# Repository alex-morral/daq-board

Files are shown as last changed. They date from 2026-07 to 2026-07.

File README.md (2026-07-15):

# DAQ Board — General-Purpose Data Acquisition Board

A 2-layer, USB-C powered **data acquisition board** built around an STM32F103,
designed from scratch in Altium, manufactured at JLCPCB, and brought up with
bare-metal firmware. It measures real-world analog signals (16-bit ADC),
generates analog output (12-bit DAC), reads temperature to ±0.1 °C, stores data
to SPI flash, and streams everything to a live browser dashboard over USB.

> Portfolio project #2 of 3 (FPGA → **PCB** → Embedded). Focus: the full
> hardware flow — schematic → layout → fabrication → bring-up → firmware.

---

## What it demonstrates

- **Mixed-signal PCB design** in Altium: analog (ADC/DAC/LDO) + digital (MCU/flash)
- **Multiple buses**: I²C, SPI, UART, USB
- **Full manufacturing flow**: DRC → Gerbers → JLCPCB assembly → DFM
- **A pin-by-pin schematic audit before paying** that caught a real error (R5)
- **Bare-metal firmware** (no HAL): direct register access, custom linker script
  and startup, driver code for every peripheral
- **A live web instrument**: Node serial bridge + WebSocket + custom canvas UI

---

## 1 · Design (Altium Designer)

The schematic — mixed-signal, six functional blocks (power, MCU, USB, I²C, SPI
flash, LEDs/SWD):

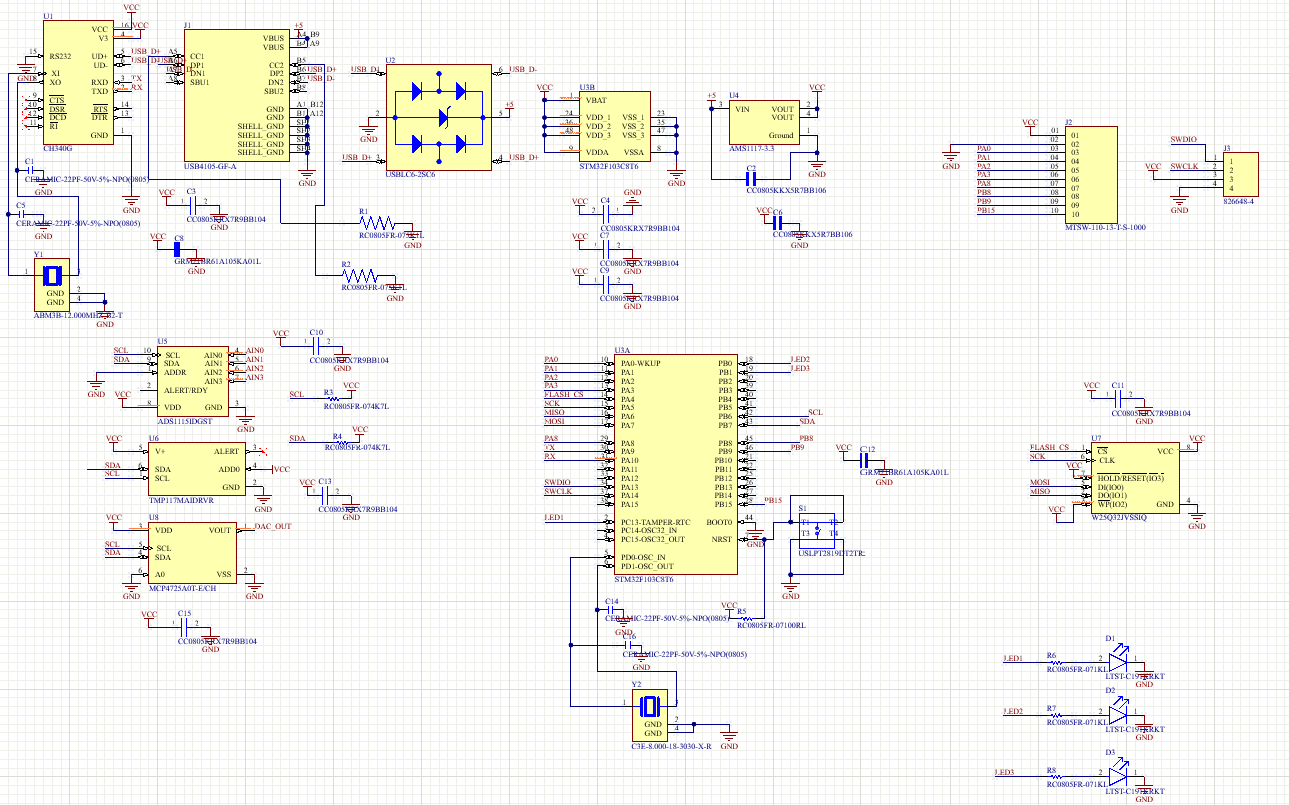
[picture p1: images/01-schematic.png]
Schematic


Board layout (2 layers, 59.94 × 40.01 mm) and 3D render:

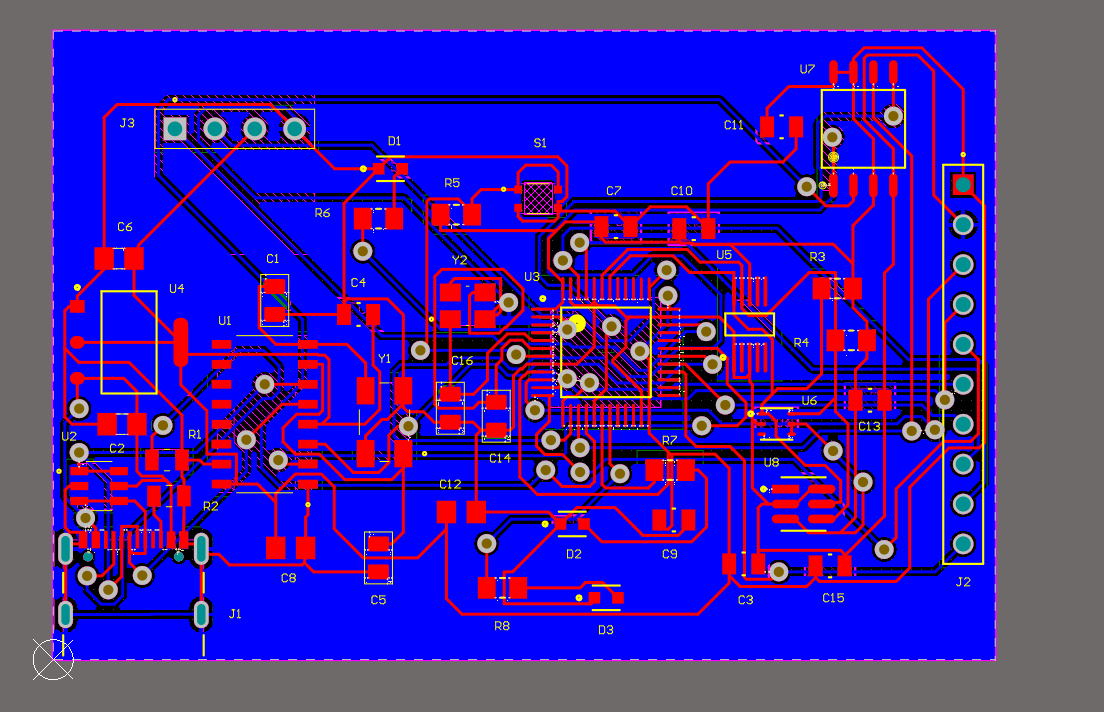
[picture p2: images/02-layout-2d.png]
2D layout

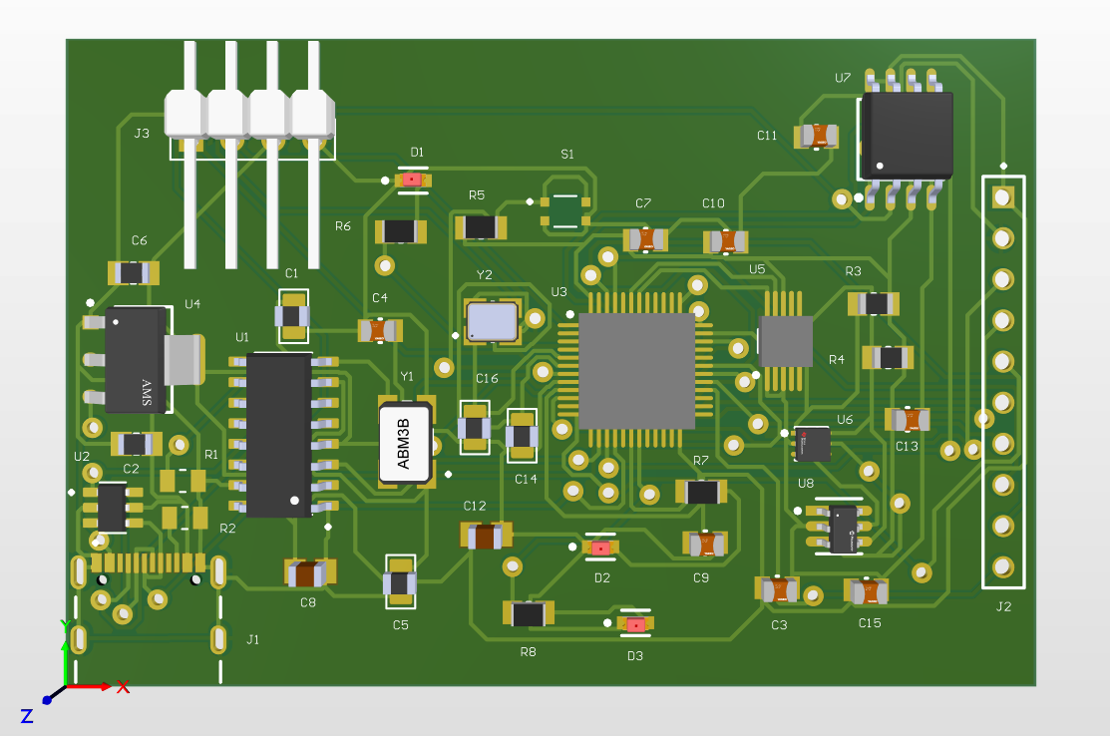
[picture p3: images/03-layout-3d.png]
3D render


Design Rule Check clean. Worth noting: the Situs auto-router reported
"135/135 100%", but DRC then revealed **23 shorts + 30 clearance violations** →
Unroute All + hand-routing to the clean result below:

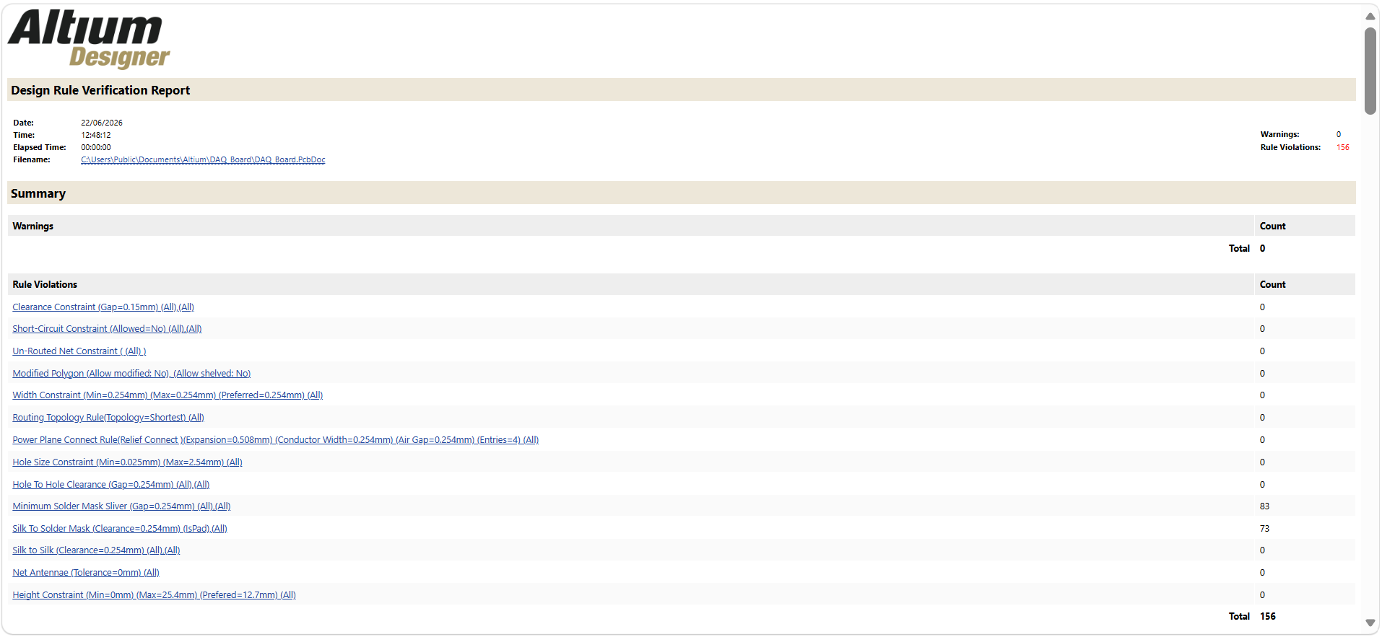
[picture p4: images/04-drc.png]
DRC clean


### The schematic audit (the interesting part)

Before paying for assembly, the whole schematic was audited **pin by pin against
datasheets**, block by block. Result: a healthy design with **one real error**.

- **Power (AMS1117):** VIN/VOUT/GND correct, tab tied to VOUT (the classic 1117
  trap — here done right), 10 µF in/out.
- **STM32:** all VDD/VDDA→VCC, VSS→GND, BOOT0→GND, clock OK.
  **🔴 R5 was 100 Ω → should be 10 kΩ (NRST pull-up). Caught and corrected.**
- **USB:** UART cross correct (CH340 RXD→TX), CH340 at 3.3 V, USBLC6 with no
  D+/D− short, R1/R2 = 5.1 kΩ.
- **I²C:** addresses verified collision-free → `0x48` / `0x49` / `0x60`
  (MCP4725 is the **A0** variant → `0x60`, *not* `0x62`). Pull-ups 4.7 kΩ.
- **SPI flash:** `/HOLD` and `/WP` tied to VCC (critical for the W25Q32).

---

## 2 · Manufacturing (JLCPCB)

DFM placement review before assembly — top and bottom:

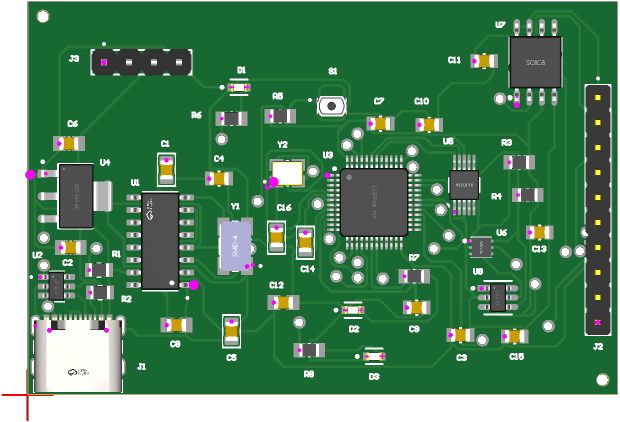
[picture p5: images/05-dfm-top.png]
DFM top

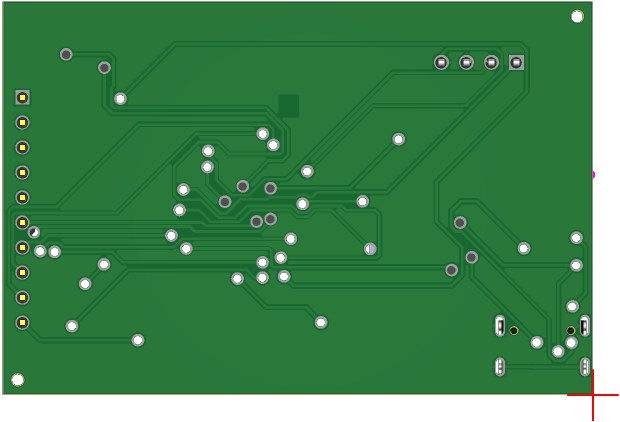
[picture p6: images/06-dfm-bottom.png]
DFM bottom


Five assembled boards, straight from the fab:

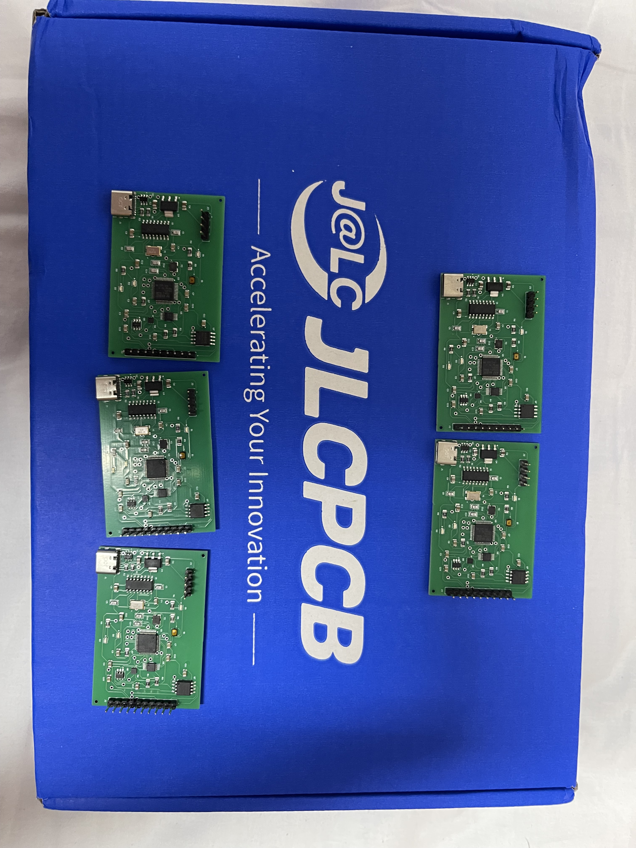
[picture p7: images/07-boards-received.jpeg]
5 assembled boards


---

## 3 · The board

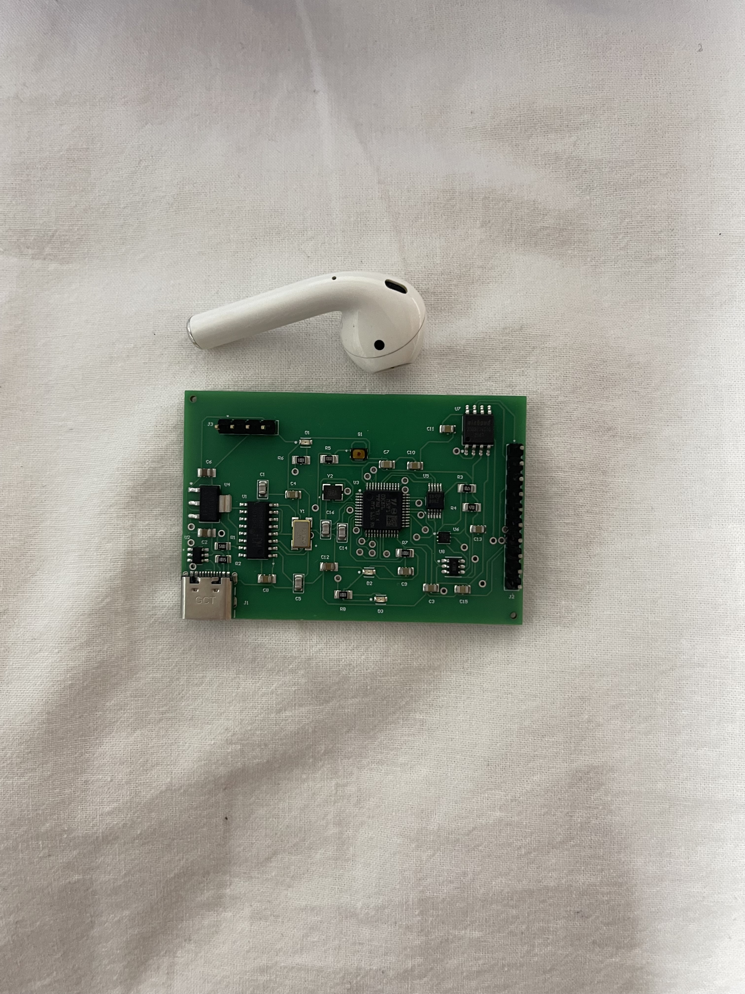
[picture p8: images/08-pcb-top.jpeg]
PCB top

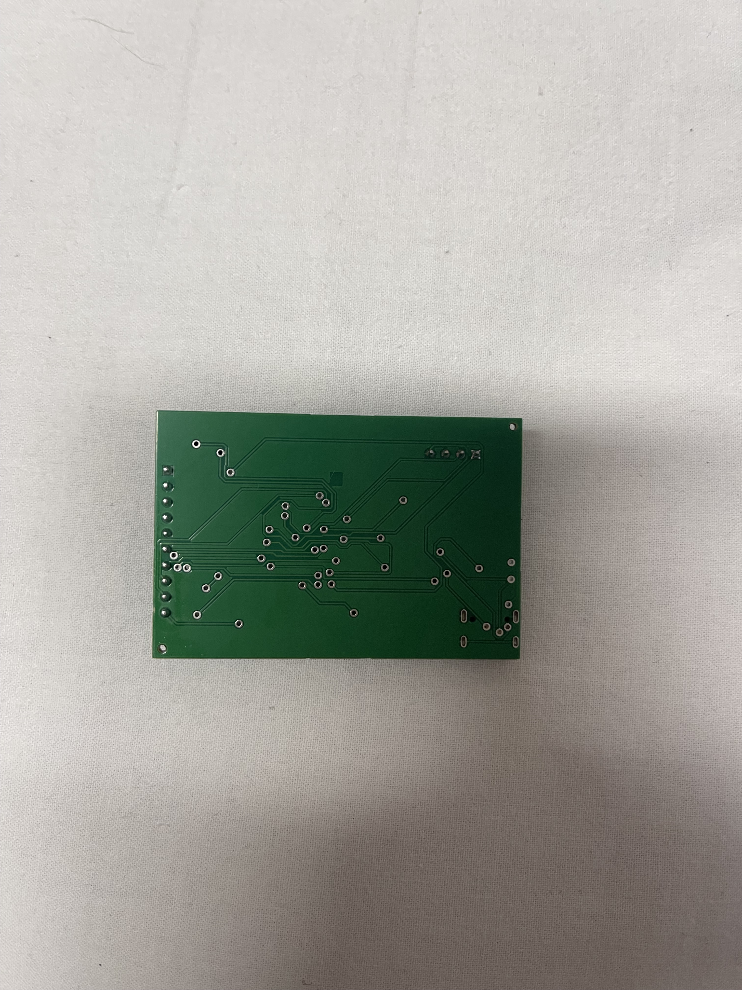
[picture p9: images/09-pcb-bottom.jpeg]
PCB bottom


| Component | Ref | Function | Bus / Address |
|---|---|---|---|
| STM32F103C8T6 | U3 | MCU (Cortex-M3, 72 MHz) | — |
| ADS1115 | U5 | 16-bit ADC, 4 channels | I²C `0x48` |
| TMP117 | U6 | Precision temp sensor (±0.1 °C) | I²C `0x49` |
| MCP4725 | U8 | 12-bit DAC | I²C `0x60` |
| W25Q32 | U7 | 4 MB SPI flash | SPI |
| CH340G | U1 | USB↔UART bridge (3.3 V) | — |
| USBLC6-2SC6 | U2 | USB ESD protection | — |
| AMS1117-3.3 | U4 | 3.3 V LDO | — |

Board: 2-layer FR-4, 1.6 mm, HASL. Assembled by JLCPCB.

---

## 4 · Bring-up

First firmware — a blinking LED validates the MCU, clock and SWD programming
path (ST-Link V2 + OpenOCD):

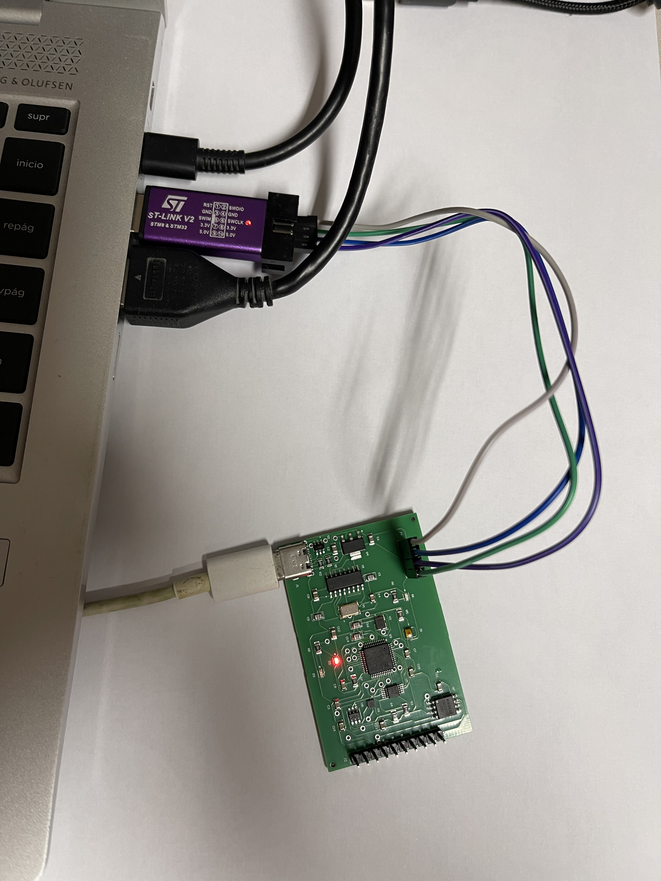
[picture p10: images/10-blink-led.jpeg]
Blink LED


Then each peripheral, one at a time. TMP117 temperature over I²C:

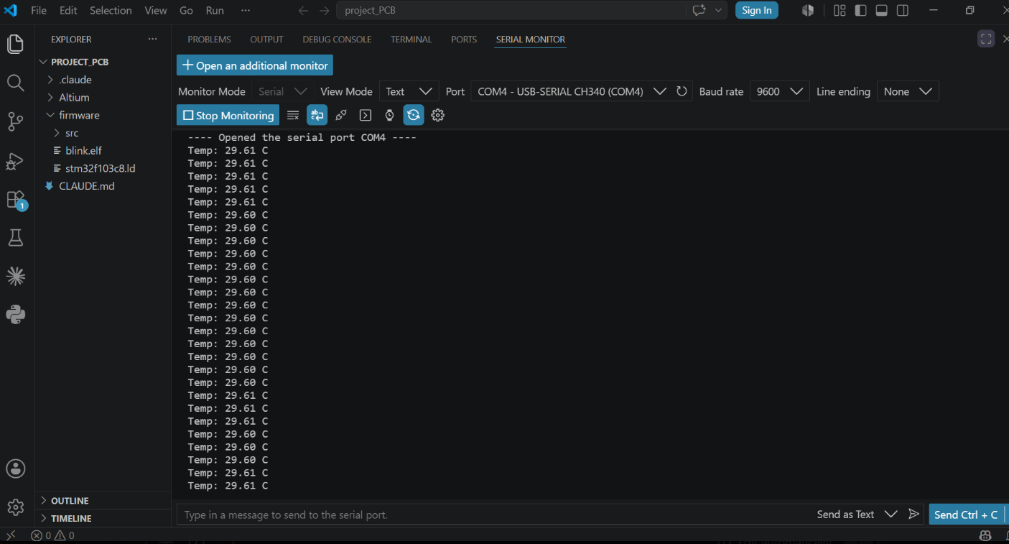
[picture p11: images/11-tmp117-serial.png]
TMP117 serial


ADS1115 ADC reading alongside the sensor:

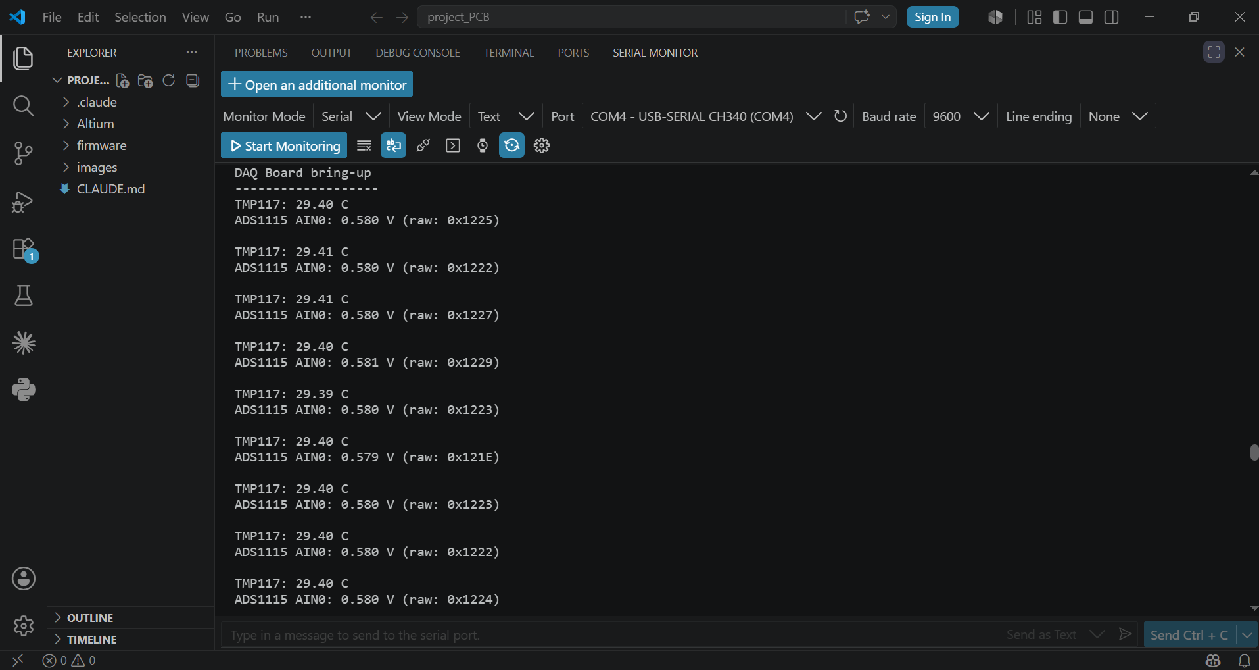
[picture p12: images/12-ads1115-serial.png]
ADS1115 serial


MCP4725 DAC output set to 1.65 V and measured with a multimeter (1.64 V — within
tolerance):

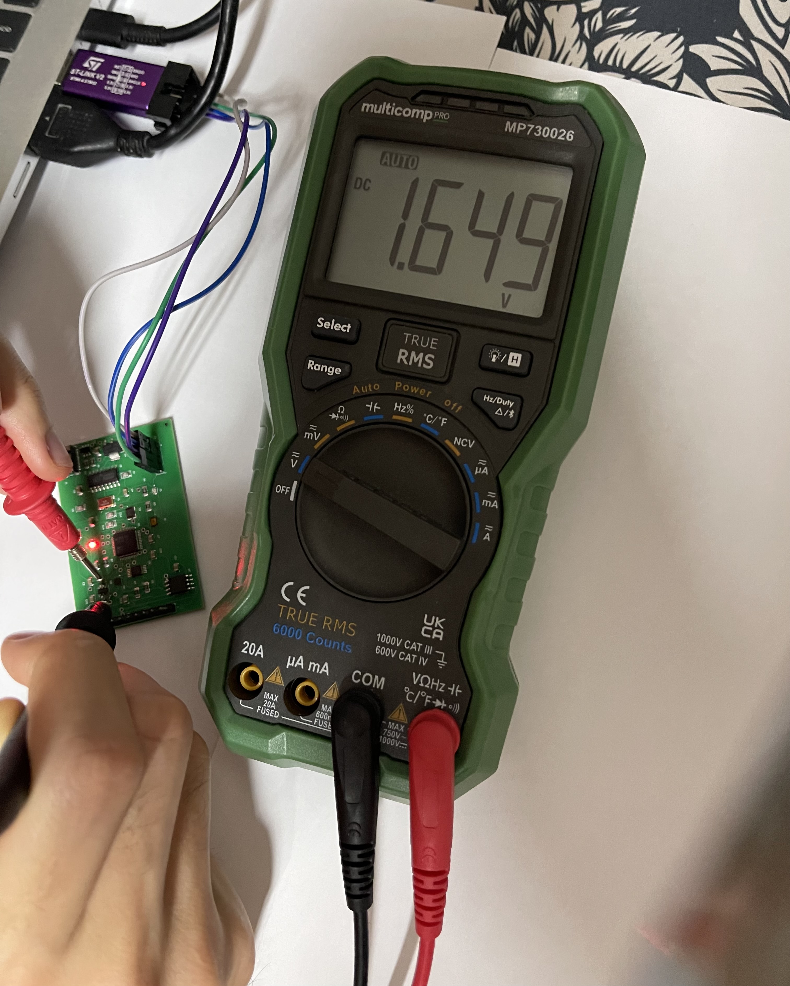
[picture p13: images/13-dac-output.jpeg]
DAC output measured


Full bring-up complete — DAC, flash (JEDEC `EF 40 16`, write/read PASS), and
live sensor data all validated:

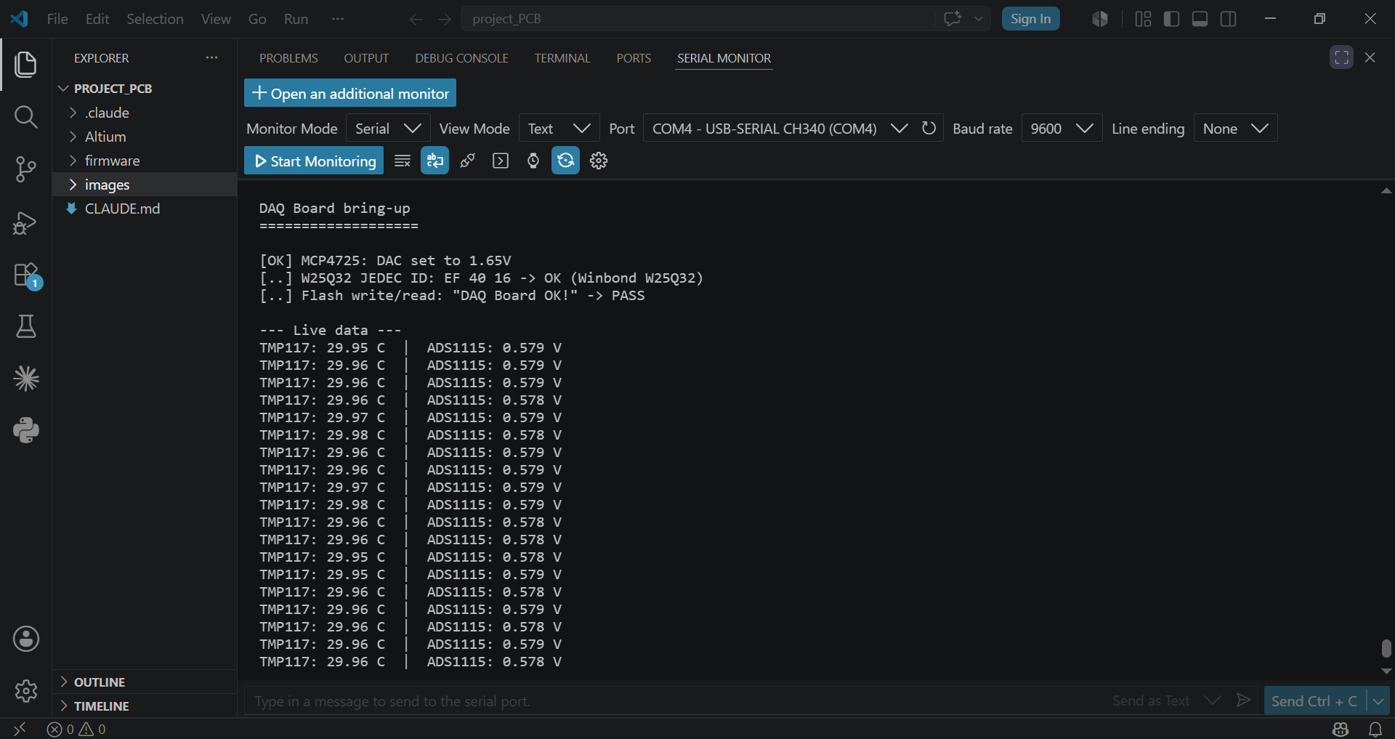
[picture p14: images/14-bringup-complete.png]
Bring-up complete


| Step | Result |
|---|---|
| Power (3.3 V rail) | ✅ measured |
| USB / CH340 enumerates | ✅ COM port |
| STM32 detected over SWD | ✅ Cortex-M3 |
| Blink LED (PB0) | ✅ MCU + crystal |
| TMP117 temperature (I²C) | ✅ ~29.6 °C stable |
| ADS1115 ADC read (I²C) | ✅ responds to PGA change |
| MCP4725 DAC output (I²C) | ✅ 1.64 V vs 1.65 V set |
| W25Q32 flash (SPI) | ✅ JEDEC `EF 40 16`, write/read PASS |

---

## 5 · Live dashboard

A Node.js bridge reads the USB serial stream and pushes it to the browser over
WebSocket; the front-end renders a test-&-measurement style instrument
(4-channel scope view, live temperature, DAC control, min/max/avg stats, CSV export).

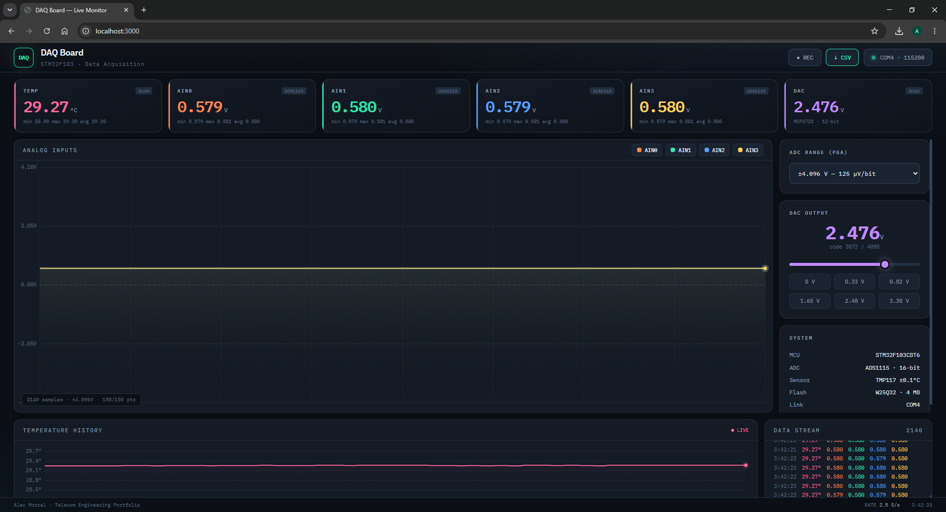
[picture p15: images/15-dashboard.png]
Live dashboard


```bash
cd dashboard
npm install
npm start            # auto-detects the CH340 port → http://localhost:3000
```

---

## Function generator (DDS)

The board doesn't just measure — it also **generates** waveforms. A hardware
timer (TIM2) ticks at a fixed sample rate; on each tick a 32-bit phase
accumulator advances and its top bits index a wavetable, whose value is written
to the DAC. This is **Direct Digital Synthesis**, the same method used in real
signal generators. Sine, square, triangle and sawtooth are selectable from the
dashboard, with adjustable frequency.

Getting reliable control while generating required moving UART reception to an
**interrupt** (`USART1_IRQHandler`): each incoming command byte is captured the
instant it arrives, so nothing is lost while the CPU is busy driving the DAC.

**Verification without an oscilloscope.** With no scope on hand, the waveforms
were validated by measuring the DAC output with a multimeter and comparing
against signal theory — the DC average is identical for all shapes (they're
centred at mid-scale), while the AC (RMS) value differs by waveform:

| Waveform | Measured AC (RMS) | Theory (A/√k) |
|---|---|---|
| DC average (all) | 1.65 V | 1.65 V (mid-scale) |
| Sine | 1.16 V | A/√2 = **1.17 V** |
| Square | ~1.6 V | A ≈ **1.65 V** |

The measured sine RMS matching A/√2 almost exactly confirms the shapes are
genuinely different, not just a changing DC level.

---

## Datalogger (on-board flash)

The board can record standalone: samples are written straight to the **W25Q32
SPI flash**, then dumped back over USB on demand. Records are 16 bytes
(index + temperature + four ADC channels), buffered a 256-byte page at a time
and written sequentially, with 4 KB sectors erased on demand as the log grows.

From the dashboard: **Record → Stop → Download** streams the stored records
back off the flash and saves them as a CSV. It's the difference between "we can
talk to the flash" (bring-up) and "the flash does a job" — the chip finally
earns its place on the board.

---

## High-speed capture (timer + DMA, software scope)

The I²C ADS1115 tops out around 860 SPS, so for fast sampling the firmware uses
the **STM32's own 12-bit ADC** on **PA0** (which *is* broken out, on the J2
header). A hardware timer (TIM3) triggers each conversion and **DMA** streams the
results straight into RAM — the CPU is idle during the capture, so the rate is
set purely by the timer (tested to tens of kSPS). A block of 480 samples is then
sent to the dashboard and drawn as a waveform: a **software oscilloscope**.

This is the "demo → serious firmware" jump: hardware-timed acquisition, DMA, and
interrupt-driven UART working together. It also gives the board a genuinely
**accessible analog input** (J2·PA0) — unlike the ADS1115's AIN pins, which this
revision does not break out. Validated with a real **LDR light sensor** wired to
J2·PA0: covering the sensor moves the captured level up and down live — a real,
physically-controllable analog input, which is exactly what the precision ADC's
inputs could not be without a board respin.

---

## System integration: PCB → FPGA → PC

The capstone. This board feeds a real-time DSP chain running on an FPGA — tying
together the three projects in my portfolio (PCB · FPGA · embedded) into one
working signal path. The STM32 generates a signal, a **Zynq FPGA filters it in
real time** with a FIR filter, and the result is plotted on the PC.

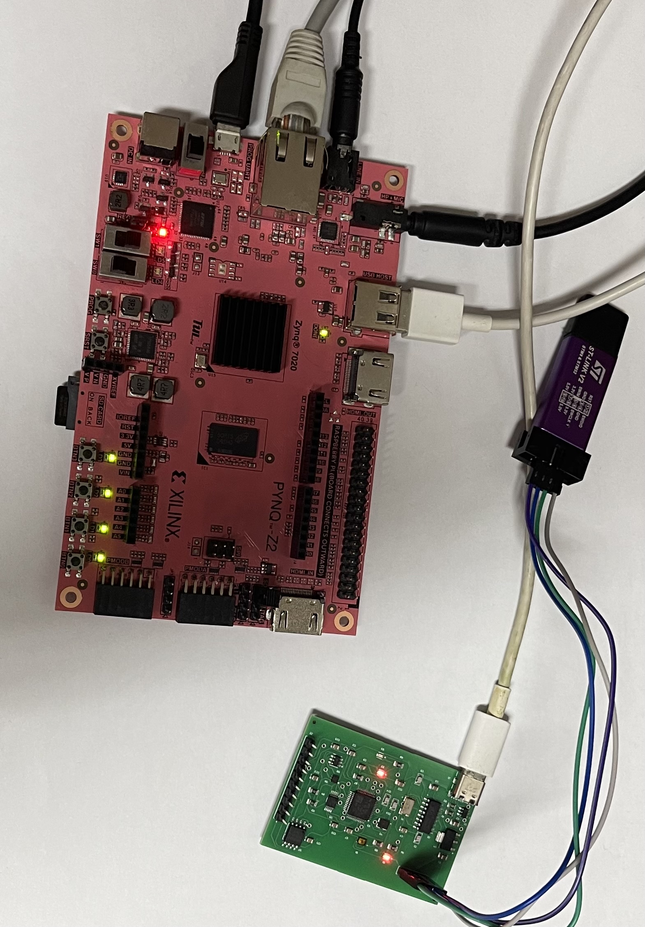
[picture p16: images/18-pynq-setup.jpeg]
DAQ Board and PYNQ-Z2 wired together


**How it works.** The board streams samples over its USB serial link into a
**PYNQ-Z2**. There, a Python script reads the samples and pushes them through a
FIR filter implemented in the FPGA fabric over **AXI4-Lite**, then reads the
filtered result back:

```
STM32 (signal)  →  USB  →  PYNQ PS (Python)  →  AXI-Lite  →  FIR in FPGA fabric
                                    ↑─────────── filtered sample ──────────┘
```

The FIR ([separate project](https://github.com/alex-morral/fir-filter-zynq),
originally fed by an I²S audio codec) needed a small RTL change to accept samples
from the processing system: a new AXI **Din** register that writes a sample into
the filter and pulses its `enable`, plus a source mux (I²S *or* AXI). The
processor-side data path is then pure Python on the PYNQ:

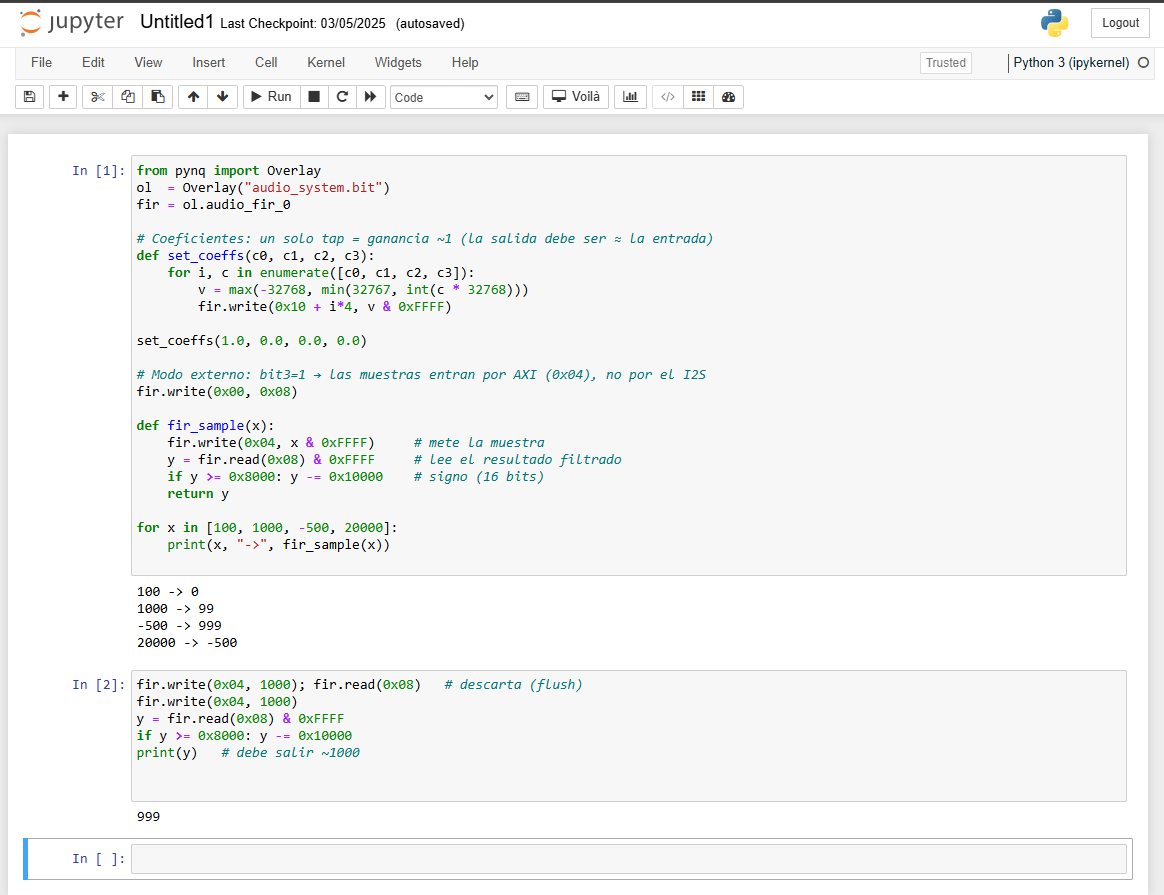
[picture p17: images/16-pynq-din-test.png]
Feeding samples to the FPGA FIR over AXI


**The result.** The STM32 generates a clean sine with a high-frequency component
added at f_s/4 (the "noise"). The FPGA's FIR — a 4-tap moving average, which
nulls f_s/4 — removes it. Input (noisy) vs output (filtered), end to end:

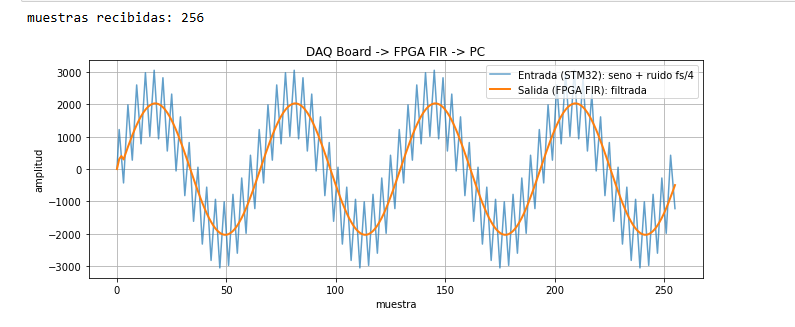
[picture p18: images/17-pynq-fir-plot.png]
Input vs FIR-filtered output


A signal **generated by my PCB**, **filtered by my FPGA**, shown on the PC — the
same acquire → process shape as a real radar / SDR / instrument front-end, built
end to end.

---

## Firmware

Bare-metal, **no HAL** — direct register access so every line is understood.

```
firmware/
├── src/
│   ├── startup.c      # vector table, reset handler, .data/.bss init
│   ├── main.c         # read sensors, drive DAC, stream over UART
│   ├── i2c.c/.h       # I²C1 driver (TMP117, ADS1115, MCP4725)
│   ├── spi.c/.h       # SPI1 driver (W25Q32)
│   └── uart.c/.h      # USART1 driver (→ CH340 → USB)
├── stm32f103c8.ld     # linker script (64 K flash, 20 K RAM)
├── Makefile           # build / flash / clean
├── build.ps1          # Windows build (no make required)
└── flash.ps1          # Windows flash via ST-Link
```

```bash
cd firmware
make            # or ./build.ps1   → build/daq.elf
make flash      # or ./flash.ps1   → program via ST-Link + OpenOCD
```

Toolchain: `arm-none-eabi-gcc` (xPack) + `openocd`. ST-Link connects to J3 (SWD).
See [docs/FIRMWARE_WALKTHROUGH.md](docs/FIRMWARE_WALKTHROUGH.md) and
[docs/DASHBOARD.md](docs/DASHBOARD.md) for a guided read of the code.

---

## Known limitations → Rev B (design analysis)

Kept as engineering notes rather than a rebuild:

- **🔴 ADC inputs not broken out.** AIN0–3 aren't routed to any header or test
  point, so external signals can't be connected without rework. For a DAQ board
  this is the #1 fix. (Found during bring-up — the ADC works, but its inputs
  float.)
- **D1 (PC13)** wired in source mode (dimmer); flip to sink in Rev B.
- VDDA unfiltered; NRST without cap; add "connect under reset" to SWD header.

---

## Roadmap

1. ~~**DAC function generator** (sine/triangle/square via HW timer)~~ ✅ done
2. ~~**Standalone datalogger** to the W25Q32, dumped over USB~~ ✅ done
3. ~~**Timer + DMA sampling** with interrupt-driven UART (kHz sample rates)~~ ✅ done
4. ~~**PYNQ-Z2 integration** — feed samples to an FPGA FIR filter (PCB → FPGA → PC)~~ ✅ done
5. **Flash-stored calibration** (offset/gain against a known reference)

---

## Author

Alex Morral — Telecommunications Electronics Engineering. Building a hardware
portfolio toward FPGA/RTL and hardware engineering roles.

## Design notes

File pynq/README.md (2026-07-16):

# PYNQ integration — DAQ Board → FPGA FIR → PC

Glue for running the board's signal through a FIR filter on a **PYNQ-Z2** FPGA.
This ties the three portfolio projects (PCB · FPGA · embedded) into one chain.

## Wiring

```
PC ── Ethernet ──▶ PYNQ-Z2            (Jupyter)
PYNQ USB host ── USB-A↔USB-C ──▶ DAQ Board   (powers the board + serial link)
```

The DAQ board's CH340 enumerates on the PYNQ as `/dev/ttyUSB0`. The board is
powered from the PYNQ's USB host port (it comes up ~20 s after boot, once Linux
enables the port).

## FPGA side (separate repo)

The FIR lives in [fir-filter-zynq](https://github.com/alex-morral/fir-filter-zynq).
It was originally fed by an I²S audio codec; to let the processing system inject
samples it needed one small RTL change in `src/audio_fir_top.vhd`:

- **control bit 3** = external mode (samples come from AXI instead of I²S),
- **register 0x04 (Din)** = write a 16-bit sample → drives the FIR input and
  pulses `enable` for one cycle,
- a source **mux** on the FIR input (I²S *or* AXI).

Rebuild the bitstream and copy `audio_system.bit` (+ the unchanged `.hwh`) to the
PYNQ next to `daq_fir_demo.py`.

The exact modified top-level used for this integration is kept here as a
reference: [`audio_fir_top.vhd`](audio_fir_top.vhd) (drop it into the FIR
project's `src/` and rebuild).

## Run

STM32 firmware must include the `SIG` command (streams a test signal); it's in
this repo's `firmware/`. Then, in a Jupyter notebook on the PYNQ:

```python
%run daq_fir_demo.py
```

It streams one block from the board, filters it in the FPGA, and plots input vs
output. The audio path (I²S, headphones) still works unchanged — the FIR just has
two selectable sources now.

## Notes / gotchas

- The PYNQ has no internet on a point-to-point Ethernet link, so `pip install
  pyserial` fails — the script reads the serial device directly (`open()` +
  `stty`), no dependency.
- `ser.flush()` after `write()` is required or the command isn't sent.
- The FIR has a 1-sample pipeline latency, flushed with a final dummy write.

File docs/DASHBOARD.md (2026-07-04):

# Dashboard walkthrough — how the live monitor works

The dashboard is three pieces connected in a line:

```
STM32 ──USB serial──▶ Node server (server.js) ──WebSocket──▶ Browser (index.html)
      ◀──DAC/PGA commands───────────────────────────────────
```

## 1. The board (firmware)

Once per loop the STM32 prints one text line over USB serial at 115200 baud:

```
T:29.60|A0:0.580|A1:0.581|A2:0.579|A3:0.580|D:2048|P:1
```

`T`=temperature, `A0..A3`=ADC channels (volts), `D`=DAC code, `P`=PGA index.
A failed reading is sent as the literal `err`.

## 2. The server (`dashboard/server.js`, Node.js)

Its job is to bridge serial ↔ browser, because a web page can't open a COM port
directly. It:

- **Auto-detects the CH340** by USB vendor ID `1a86` (`SerialPort.list()`), so
  you don't hard-code COM3/COM4.
- Reads lines, **parses** them into a JSON object (turning `err` into `null`).
- **Broadcasts** each sample to all connected browsers over WebSocket.
- Forwards `DAC:`/`PGA:` commands from the browser back to the serial port.
- **Reconnects** automatically if the board is unplugged (it no longer crashes).

Messages sent to the browser are tagged: `{type:'status', connected, port}` for
link state and `{type:'sample', temperature, channels[], dac, pga}` for data.

## 3. The browser (`dashboard/public/index.html`)

A single self-contained page (HTML + CSS + vanilla JS, no framework):

- Opens a **WebSocket** to the server and listens for messages.
- `status` messages drive the connection indicator.
- `sample` messages update the six **measurement tiles**, the **4-channel scope**
  (drawn on a `<canvas>`), the **temperature chart**, running **min/max/avg**
  statistics, and the **data-stream log**.
- Moving the **DAC slider** or changing the **PGA** sends a command back through
  the WebSocket → server → board.
- **REC** buffers samples; **CSV** exports them as a file.
- A `null` (error) reading shows as **ERR** in red instead of a fake number.

## Run it

```
cd dashboard
npm install
npm start          # auto-detects the port → http://localhost:3000
```

If auto-detect ever fails, pass the port explicitly: `node server.js COM4`.

## Why this architecture?

It's the same shape as professional test software: the instrument speaks a
simple line protocol, a host process bridges the transport, and the UI is
decoupled from the hardware. You could swap the browser for a Python client, or
the serial link for TCP, without touching the firmware.

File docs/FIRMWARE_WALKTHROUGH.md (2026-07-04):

# Firmware walkthrough — how it all works

A guided read of the bare-metal firmware, written so you can understand every
line and then modify it yourself. No HAL, no libraries — just the STM32F103
reference manual and C.

> Read this with the source open in split view. Order: `startup.c` →
> `stm32f103c8.ld` → `uart.c` → `i2c.c` → `spi.c` → `main.c`.

---

## 0. The one idea behind everything: memory-mapped registers

On a microcontroller, hardware is controlled by **writing to fixed memory
addresses**. Each peripheral (GPIO, I²C, UART…) has a block of 32-bit
"registers" at a known address. Writing a bit turns something on; reading a bit
tells you a status.

Example from the code:

```c
#define GPIOB_BASE  0x40010C00
#define GPIOB_ODR  (*(volatile uint32_t *)(GPIOB_BASE + 0x0C))
GPIOB_ODR ^= (1 << 0);   // toggle bit 0 of port B output → toggles PB0 (LED2)
```

- `0x40010C00` is where GPIOB lives (from the reference manual memory map).
- `+ 0x0C` is the offset of the **ODR** (Output Data Register).
- `*(volatile uint32_t *)ADDR` means "treat this address as a 32-bit register".
- `volatile` tells the compiler *never* to optimise the access away — the value
  can change because of hardware, not just code.

Every driver in this project is just: enable the peripheral's clock, configure
its pins, write config registers, then read/write data registers. That's it.

---

## 1. `startup.c` — what runs before `main()`

When the STM32 powers up it does **not** jump straight to `main()`. It reads the
**vector table** — an array of addresses at the very start of flash:

```c
__attribute__((section(".isr_vector")))
void (*const vectors[])(void) = {
    (void (*)(void))(&_estack),  // [0] initial stack pointer
    Reset_Handler,               // [1] where the CPU starts executing
    ...
};
```

- Entry 0 = initial **stack pointer** value.
- Entry 1 = **Reset_Handler**, the first code that runs.
- The rest are fault/interrupt handlers (we point them at `Default_Handler`
  because this firmware uses no interrupts).

`Reset_Handler` does the C runtime setup the compiler assumes exists:

```c
void Reset_Handler(void) {
    // copy initialised globals from flash → RAM (.data)
    // zero uninitialised globals (.bss)
    main();
    while (1);   // never return
}
```

Globals with a value live in flash but must be *copied* to RAM before `main`;
zero-initialised globals must be *cleared*. On a PC the OS does this — here we do
it by hand. `_sdata`, `_edata`, `_sbss`… come from the linker script (next).

We also define our own `memset` because with `-nostdlib` there's no C library.

---

## 2. `stm32f103c8.ld` — the memory map

The linker script tells the compiler **where things go** in the chip:

```
MEMORY {
  FLASH (rx)  : ORIGIN = 0x08000000, LENGTH = 64K   /* code + constants */
  RAM   (rwx) : ORIGIN = 0x20000000, LENGTH = 20K   /* variables + stack */
}
```

- **Flash** (0x0800_0000): non-volatile, holds the program. 64 KB on the C8 part.
- **RAM** (0x2000_0000): volatile, holds variables and the stack. 20 KB.

The `SECTIONS` block places code (`.text`), constants (`.rodata`), initialised
data (`.data`) and zero data (`.bss`), and exports the symbols
(`_sdata`, `_sbss`, `_estack`…) that `startup.c` uses. `_estack` is set to the
top of RAM because the Cortex-M stack grows downward.

---

## 3. `uart.c` — talking to the PC

USART1 sends bytes to the CH340 chip, which turns them into USB serial (your COM
port). Setup:

1. Enable clocks for GPIOA and USART1 (`RCC_APB2ENR`).
2. Configure PA9 as TX (alternate-function push-pull), PA10 as RX (input).
3. Set the **baud rate** via `BRR = clock / baud`. At 8 MHz for 115200 →
   `8_000_000 / 115200 ≈ 69 = 0x45`.
4. Enable the USART.

Sending a byte is a two-step handshake:

```c
void uart_send_char(char c){
    while (!(USART1_SR & (1 << 7)));  // wait until TXE (transmit buffer empty)
    USART1_DR = c;                     // write the byte
}
```

This is **blocking** — the CPU spins until the byte can be queued. Fine here;
the "roadmap" replaces it with interrupt/DMA-driven TX for higher throughput.

---

## 4. `i2c.c` — the sensor/DAC bus

I²C is a 2-wire bus (SCL clock, SDA data) shared by the TMP117, ADS1115 and
MCP4725. Each device has a 7-bit address (0x49, 0x48, 0x60). A transaction is a
sequence of hardware events you drive through registers and wait on via status
flags:

```
START → send address+W → send register → repeated START → address+R → read bytes → STOP
```

`wait_flag()` polls a status bit with a timeout so a missing device can't hang
the firmware forever. **Robustness added in the audit:**

- `i2c_abort()` fires a STOP on every error path, so a failed transfer releases
  the bus instead of leaving SCL/SDA latched.
- `i2c_ensure_ready()` runs before each transaction: if the peripheral is stuck
  BUSY, it software-resets and re-initialises the I²C block (self-heal).

Without these, one NAK from a device could wedge the bus and every later read
would fail until a full reset.

---

## 5. `spi.c` — the flash memory

SPI is faster and simpler than I²C: separate lines for clock (SCK), data out
(MOSI), data in (MISO), plus a chip-select (CS) we drive by hand on PA4. A
transfer is full-duplex — you send and receive a byte at the same time:

```c
uint8_t spi_transfer(uint8_t data){
    while (!(SPI1_SR & (1<<1)));  // TXE: ok to write
    SPI1_DR = data;
    while (!(SPI1_SR & (1<<0)));  // RXNE: a byte came back
    return SPI1_DR;
}
```

The W25Q32 flash speaks a command protocol on top of this: `0x9F` reads the
JEDEC ID, `0x06` write-enable, `0x20` erase a 4 KB sector, `0x02` program a page,
`0x03` read. The bring-up test does erase → write "DAQ Board OK!" → read-back.

---

## 6. `main.c` — the application

Now the pieces combine. `main()`:

1. Inits UART, I²C, SPI and the status LEDs.
2. Prints a banner, sets the DAC to mid-scale, checks the flash ID.
3. Loops forever:
   - read TMP117 temperature (I²C),
   - read all 4 ADS1115 channels (`read_adc_channel`),
   - print one line `T:..|A0:..|A1:..|A2:..|A3:..|D:..|P:..`,
   - update the status LEDs,
   - short delay.

Two functions worth understanding:

**`read_adc_channel()`** — writes the ADS1115 config (which channel, gain,
single-shot), then **polls the OS bit** until the conversion is done before
reading the result. (Earlier it used a blind delay, which could read a stale
sample — fixed in the audit.) On any I²C failure it returns `ADC_ERR`.

**`send_voltage()`** — converts the raw 16-bit code to volts. The gain (PGA)
sets how many microvolts each bit is worth (`lsb_nv[]`). The multiply is done in
`int64_t` because `32767 × 187500` overflows a 32-bit int — a real bug caught in
the audit. If the reading was `ADC_ERR`, it prints `err` so the dashboard can
show a fault instead of a fake number.

### The command channel

The PC can talk back. `check_uart_rx()` reads incoming bytes into a buffer; on a
newline, `process_command()` parses:

- `DAC:<0-4095>` → set the DAC output voltage,
- `PGA:<0-5>` → change the ADC input range.

`check_uart_rx()` is called inside `delay()` too, so commands are handled even
while the loop is waiting.

---

## How to change something (try it)

- **Blink faster**: change the `delay(...)` at the bottom of the main loop.
- **Different LED**: `main.c` drives PB0/PB1/PC13 — swap the pin bits.
- **New command**: add another `if` in `process_command()` (e.g. `LED:1`).
- **Log to flash**: use the `flash_write_page`/`flash_read` helpers to store the
  ADC samples — that's roadmap item #2.

Build and flash after any change:

```
./build.ps1     # or: make
./flash.ps1     # or: make flash   (ST-Link on J3)
```

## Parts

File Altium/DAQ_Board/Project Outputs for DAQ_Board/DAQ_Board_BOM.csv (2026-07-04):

Comment | Designator | Footprint | JLCPCB Part #
TMP117MAIDRVR | U6 | FP-DRV0006B-IPC_C | C2803242
USBLC6-2SC6 | U2 | SOT95P280X145-6N | C2827654
GRM21BR61A105KA01L | C8,C12 | CAPC2012X135N | C28323
USB4105-GF-A | J1 | GCT_USB4105-GF-A | C3020560
MTSW-110-13-T-S-1000 | J2 | SAMTEC_MTSW-110-13-T-S-1000 | C5383117
CC0805KRX7R9BB104 | C3,C4,C7,C9,C10,C11,C13,C15 | FP-CC0805-0_85-MFG | C49678
LTST-C191KRKT | D1,D2,D3 | FP-LTST-C191KRKT-MFG | C125099
STM32F103C8T6 | U3 | STM-LQFP48_L | C8734
826648-4 | J3 | TE_826648-4 | C5346656
ABM3B-12.000MHZ-B2-T | Y1 | XTAL_ABM3B-12.000MHZ-B2-T | C596868
0805W8F1002T5E | R5 | RESC2013X60X35ML10T20 | C17414
CH340G | U1 | SOIC127P600X180-16N | C14267
MCP4725A0T-E/CH | U8 | FP-C04-028-CHY-IPC_A | C144198
C3E-8.000-18-3030-X-R | Y2 | XTAL_C3E-8.000-18-3030-X-R | C57131
RC0805FR-071KL | R6,R7,R8 | RESC2013X60X35ML10T20 | C95781
W25Q32JVSSIQ | U7 | SOIC127P790X216-8N | C179173
CC0805KKX5R7BB106 | C2,C6 | CAPC2012X70 | C15850
AMS1117-3.3 | U4 | FP-AMS1117-IPC_C | C6186
CERAMIC-22PF-50V-5%-NPO(0805) | C1,C5,C14,C16 | C0805 | C668358
RC0805FR-074K7L | R3,R4 | YAGO-RC0805_M | C17673
USLPT2819DT2TR | S1 | SW_USLPT2819DT2TR | C6734770
ADS1115IDGST | U5 | TI-DGS10_M | C468683
RC0805FR-075K1L | R1,R2 | RESC2012X60N | C84375

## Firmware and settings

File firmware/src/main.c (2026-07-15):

#include <stdint.h>
#include "i2c.h"
#include "uart.h"
#include "spi.h"
#include "timer.h"
#include "hsadc.h"

#define GPIOB_BASE      0x40010C00
#define GPIOB_CRL       (*(volatile uint32_t *)(GPIOB_BASE + 0x00))
#define GPIOB_ODR       (*(volatile uint32_t *)(GPIOB_BASE + 0x0C))

#define GPIOC_BASE      0x40011000
#define GPIOC_CRH       (*(volatile uint32_t *)(GPIOC_BASE + 0x04))
#define GPIOC_ODR       (*(volatile uint32_t *)(GPIOC_BASE + 0x0C))

#define RCC_BASE2       0x40021000
#define RCC_APB2ENR2    (*(volatile uint32_t *)(RCC_BASE2 + 0x18))

// Status LEDs: D1=PC13 (source mode, dim), D2=PB0 (heartbeat), D3=PB1 (comms)
#define LED_DAC_ON()    (GPIOC_ODR |=  (1 << 13))   // D1 on
#define LED_DAC_OFF()   (GPIOC_ODR &= ~(1 << 13))   // D1 off
#define LED_HB_TOGGLE() (GPIOB_ODR ^=  (1 << 0))    // D2 toggle
#define LED_COMM_ON()   (GPIOB_ODR |=  (1 << 1))    // D3 on
#define LED_COMM_OFF()  (GPIOB_ODR &= ~(1 << 1))    // D3 off

#define USART1_BASE     0x40013800
#define USART1_SR       (*(volatile uint32_t *)(USART1_BASE + 0x00))
#define USART1_DR       (*(volatile uint32_t *)(USART1_BASE + 0x04))

#define TMP117_ADDR     0x49
#define TMP117_TEMP_REG 0x00

#define ADS1115_ADDR    0x48
#define ADS1115_CONV    0x00
#define ADS1115_CONFIG  0x01

#define MCP4725_ADDR    0x60

static uint16_t dac_value = 2048;
static uint8_t adc_pga = 1; // 0=6.144V, 1=4.096V, 2=2.048V, 3=1.024V, 4=0.512V, 5=0.256V

// PGA LSB sizes in nanovolts, indexed by pga setting
// (187.5, 125, 62.5, 31.25, 15.625, 7.8125 uV/bit)
static const int32_t lsb_nv[] = { 187500, 125000, 62500, 31250, 15625, 7813 };

// Sentinel returned when an ADC / I2C read fails, so the host can tell a real
// measurement from a bus error instead of showing a plausible-looking voltage.
#define ADC_ERR  0x7FFFFFFF

static int mcp4725_write(uint16_t value_12bit) {
    uint8_t data[2];
    data[0] = (value_12bit >> 8) & 0x0F;
    data[1] = value_12bit & 0xFF;
    return i2c_write_bytes(MCP4725_ADDR, data, 2);
}

// ---------------------------------------------------------------------------
// Function generator (DAC + timer, Direct Digital Synthesis)
//
// A hardware timer ticks at a fixed sample rate GEN_FS. On each tick a 32-bit
// phase accumulator advances by a "tuning word"; its top 6 bits index a
// 64-point wavetable, and that value is written to the DAC. Output frequency =
// tuning_word / 2^32 * GEN_FS, so we get fine frequency control from one table.
// This is exactly how a DDS signal generator works.
// ---------------------------------------------------------------------------
#define GEN_FS   2000u    // DAC update rate (Hz); bounded by I2C write time

// One cycle of a sine, 64 points, scaled to the 12-bit DAC range (0..4095).
static const uint16_t sine64[64] = {
    2048,2249,2447,2642,2831,3013,3185,3347,3495,3630,3750,3853,3939,4007,4056,4085,
    4095,4085,4056,4007,3939,3853,3750,3630,3495,3347,3185,3013,2831,2642,2447,2249,
    2048,1847,1649,1454,1265,1083, 911, 749, 601, 466, 346, 243, 157,  89,  40,  11,
       1,  11,  40,  89, 157, 243, 346, 466, 601, 749, 911,1083,1265,1454,1649,1847
};

// High-speed capture buffer (internal ADC on PA0, filled by timer+DMA).
#define HS_N 480
static uint16_t hs_buf[HS_N];

static volatile uint8_t  gen_mode  = 0;   // 0=off 1=sine 2=square 3=triangle 4=saw
static volatile uint16_t gen_freq  = 0;   // requested output frequency (Hz)
static uint32_t gen_phase = 0;            // DDS phase accumulator
static uint32_t gen_tw    = 0;            // DDS tuning word

// PYNQ demo: stream a digital test signal over UART = clean low sine + a
// high-frequency component at fs/4 (the "noise" the FPGA FIR will remove).
#define SIG_N 256
static volatile uint8_t sig_mode = 0;     // 1 = stream FX: blocks for the PYNQ

static void gen_set(uint8_t mode, uint16_t freq) {
    if (freq > 500) freq = 500;           // keep waveforms well-sampled
    gen_mode = mode;
    gen_freq = freq;
    gen_phase = 0;
    // tuning_word = freq * 2^32 / Fs  (64-bit avoids overflow)
    gen_tw = (uint32_t)(((uint64_t)freq << 32) / GEN_FS);
    if (mode == 0) mcp4725_write(dac_value);   // restore manual DAC level
}

// Produce one output sample from the current phase, per waveform.
static uint16_t gen_sample(void) {
    uint32_t p = gen_phase;
    switch (gen_mode) {
        case 1: return sine64[p >> 26];                     // sine (table)
        case 2: return (p & 0x80000000u) ? 4095 : 0;        // square
        case 3: {                                            // triangle
            uint32_t s = p >> 20;                            // 0..4095
            return s < 2048 ? (s * 2) : ((4095 - s) * 2);
        }
        case 4: return p >> 20;                              // sawtooth
        default: return dac_value;
    }
}

// Datalogger controls (defined below main's helpers, forward-declared here so
// the command parser can call them).
static void log_start(void);
static void log_stop(void);
static void log_dump(void);

// A completed command line, filled by the USART1 interrupt and consumed by the
// main loop. The ISR only buffers text (never touches I2C), so the main loop is
// free to run the actual command — which does I2C — at a safe point.
static volatile char    cmd_buf[24];
static volatile uint8_t cmd_ready = 0;
static volatile int     comm_activity = 0;

// USART1 receive interrupt: captures each incoming byte the moment it arrives,
// so no command byte is ever lost, even while the main loop is busy driving the
// DAC. Assembles bytes into a line and flags it complete on newline.
void USART1_IRQHandler(void) {
    static char line[24];
    static uint8_t idx = 0;
    while (USART1_SR & (1 << 5)) {          // RXNE: a byte is waiting
        char c = USART1_DR;                  // reading DR clears the flag
        if (c == '\n' || c == '\r') {
            if (idx > 0) {
                for (uint8_t i = 0; i < idx; i++) cmd_buf[i] = line[i];
                cmd_buf[idx] = 0;            // null-terminate
                cmd_ready = 1;
                idx = 0;
            }
        } else if (idx < sizeof(line) - 1) {
            line[idx++] = c;
        }
    }
}

// Parse and act on the last completed command (runs in main context, so I2C is
// safe here). cmd_buf is a null-terminated string like "DAC:2048" or "GEN:1:50".
static void process_command(void) {
    comm_activity = 8;  // light D3 for next 8 loop iterations
    const volatile char *b = cmd_buf;

    if (b[0]=='D' && b[1]=='A' && b[2]=='C' && b[3]==':') {
        uint16_t val = 0;
        for (int i = 4; b[i]; i++)
            if (b[i] >= '0' && b[i] <= '9') val = val * 10 + (b[i] - '0');
        if (val > 4095) val = 4095;
        dac_value = val;
        mcp4725_write(dac_value);
    }
    else if (b[0]=='P' && b[1]=='G' && b[2]=='A' && b[3]==':') {
        uint8_t val = b[4] - '0';
        if (val <= 5) adc_pga = val;
    }
    // GEN:<mode>:<freq>  e.g. "GEN:1:50" = sine 50 Hz, "GEN:0" = off
    else if (b[0]=='G' && b[1]=='E' && b[2]=='N' && b[3]==':') {
        uint8_t mode = b[4] - '0';
        uint16_t freq = 0;
        int i = 5;
        if (b[i] == ':') i++;                            // skip separator
        for (; b[i]; i++)
            if (b[i] >= '0' && b[i] <= '9') freq = freq * 10 + (b[i] - '0');
        if (mode <= 4) gen_set(mode, freq);
    }
    // LOG:1 = start, LOG:0 = stop, LOG:2 = dump over USB
    else if (b[0]=='L' && b[1]=='O' && b[2]=='G' && b[3]==':') {
        uint8_t op = b[4] - '0';
        if (op == 1) log_start();
        else if (op == 0) log_stop();
        else if (op == 2) log_dump();
    }
    // SIG:1 = stream test-signal blocks to the PYNQ, SIG:0 = stop
    else if (b[0]=='S' && b[1]=='I' && b[2]=='G' && b[3]==':') {
        sig_mode = (b[4] == '1');
    }
    // CAP:<rate> = capture HS_N samples of PA0 at <rate> Hz (timer+DMA) and
    // stream them back as "CB:<rate>:<n>:v0,v1,...". A software oscilloscope.
    else if (b[0]=='C' && b[1]=='A' && b[2]=='P' && b[3]==':') {
        uint32_t rate = 0;
        for (int i = 4; b[i]; i++)
            if (b[i] >= '0' && b[i] <= '9') rate = rate * 10 + (b[i] - '0');
        if (rate < 100) rate = 100;
        if (rate > 100000) rate = 100000;
        hsadc_capture(hs_buf, HS_N, rate);
        uart_send_string("CB:");
        uart_send_int(rate);
        uart_send_char(':');
        uart_send_int(HS_N);
        uart_send_char(':');
        for (int i = 0; i < HS_N; i++) {
            uart_send_int(hs_buf[i] & 0x0FFF);   // 12-bit sample
            if (i < HS_N - 1) uart_send_char(',');
        }
        uart_send_string("\r\n");
    }
}

// Run any pending command. Called from safe points in the main loop.
static void poll_command(void) {
    if (cmd_ready) {
        process_command();
        cmd_ready = 0;
    }
}

void delay(volatile uint32_t count) {
    while (count--);
}

// Read one single-ended ADC channel. Returns the signed 16-bit code, or
// ADC_ERR if any I2C transaction fails. Waits for the conversion by polling
// the ADS1115 OS bit (config reg bit 15 = 1 when the conversion is done),
// instead of a blind delay that could return a stale sample.
static int32_t read_adc_channel(uint8_t channel) {
    // MUX: 100=AIN0, 101=AIN1, 110=AIN2, 111=AIN3 (single-ended vs GND)
    uint16_t mux = (0x04 + channel) << 12;
    uint16_t pga = (uint16_t)adc_pga << 9;
    // OS=1 (start), MODE=1 (single-shot), DR=100 (128SPS), COMP=11
    uint16_t cfg = (1 << 15) | mux | pga | (1 << 8) | (0x4 << 5) | 0x03;

    if (i2c_write_reg16(ADS1115_ADDR, ADS1115_CONFIG, cfg) != 0)
        return ADC_ERR;

    // Poll OS bit until conversion complete (bounded, ~few ms at 128 SPS)
    uint16_t status = 0;
    for (int tries = 0; tries < 50; tries++) {
        if (i2c_read_reg16(ADS1115_ADDR, ADS1115_CONFIG, &status) != 0)
            return ADC_ERR;
        if (status & 0x8000) break;   // OS=1 -> ready
        delay(2000);
    }

    uint16_t raw = 0;
    if (i2c_read_reg16(ADS1115_ADDR, ADS1115_CONV, &raw) != 0)
        return ADC_ERR;

    return (int16_t)raw;   // sign-extend 16-bit code
}

// Print a channel value as signed volts (e.g. "1.650", "-0.012") or "err".
static void send_voltage(int32_t raw) {
    if (raw == ADC_ERR) { uart_send_string("err"); return; }

    // 64-bit multiply avoids int32 overflow (32767 * 187500 > 2^31)
    int64_t nv = (int64_t)raw * lsb_nv[adc_pga];   // nanovolts
    int32_t mv = (int32_t)(nv / 1000000);          // millivolts, range -6144..6144

    if (mv < 0) { uart_send_char('-'); mv = -mv; }
    int volts = mv / 1000;
    int frac  = mv % 1000;
    uart_send_int(volts);
    uart_send_char('.');
    if (frac < 100) uart_send_char('0');
    if (frac < 10)  uart_send_char('0');
    uart_send_int(frac);
}

// ---------------------------------------------------------------------------
// Datalogger — stream samples to the on-board W25Q32 flash, dump over USB.
// Records are 16 bytes, buffered one 256-byte page (16 records) at a time and
// written sequentially; 4 KB sectors are erased on demand as we advance.
// Record layout: [0..3] index  [4..5] temp x100  [6..13] 4x ADC millivolts.
// ---------------------------------------------------------------------------

// --- W25Q32 command set, on top of the SPI driver ---
static void flash_write_enable(void) {
    flash_cs_low(); spi_transfer(0x06); flash_cs_high();
}
static void flash_wait_busy(void) {
    flash_cs_low(); spi_transfer(0x05);
    while (spi_transfer(0x00) & 0x01);              // poll BUSY bit
    flash_cs_high();
}
static void flash_erase_sector(uint32_t addr) {
    flash_write_enable();
    flash_cs_low();
    spi_transfer(0x20);                             // 4 KB sector erase
    spi_transfer(addr >> 16); spi_transfer(addr >> 8); spi_transfer(addr);
    flash_cs_high();
    flash_wait_busy();
}
static void flash_write_page(uint32_t addr, const uint8_t *data, int len) {
    flash_write_enable();
    flash_cs_low();
    spi_transfer(0x02);                             // page program
    spi_transfer(addr >> 16); spi_transfer(addr >> 8); spi_transfer(addr);
    for (int i = 0; i < len; i++) spi_transfer(data[i]);
    flash_cs_high();
    flash_wait_busy();
}
static void flash_read(uint32_t addr, uint8_t *buf, int len) {
    flash_cs_low();
    spi_transfer(0x03);                             // read data
    spi_transfer(addr >> 16); spi_transfer(addr >> 8); spi_transfer(addr);
    for (int i = 0; i < len; i++) buf[i] = spi_transfer(0x00);
    flash_cs_high();
}

#define REC_SIZE   16
#define FLASH_SIZE (4u * 1024 * 1024)
static uint8_t  logging   = 0;
static uint32_t rec_count = 0;
static uint32_t log_addr  = 0;                      // next flash byte to write
static uint8_t  page_buf[256];
static uint16_t page_fill = 0;

static int16_t adc_to_mv(int32_t raw) {
    if (raw == ADC_ERR) return 0x7FFF;              // error sentinel
    return (int16_t)(((int64_t)raw * lsb_nv[adc_pga]) / 1000000);
}

static void log_flush_page(void) {
    if (page_fill == 0) return;
    while (page_fill < 256) page_buf[page_fill++] = 0xFF;   // pad to full page
    if ((log_addr % 4096) == 0) flash_erase_sector(log_addr);
    flash_write_page(log_addr, page_buf, 256);
    log_addr += 256;
    page_fill = 0;
}

static void log_start(void) {
    logging = 1; rec_count = 0; log_addr = 0; page_fill = 0;
}
static void log_stop(void) {
    log_flush_page();                              // commit the last partial page
    logging = 0;
}
static void log_append(int16_t temp_x100, const int32_t ch[4]) {
    if (log_addr + 256 >= FLASH_SIZE) { log_stop(); return; }   // flash full
    uint8_t *r = &page_buf[page_fill];
    r[0]=rec_count; r[1]=rec_count>>8; r[2]=rec_count>>16; r[3]=rec_count>>24;
    r[4]=temp_x100; r[5]=temp_x100>>8;
    for (int i = 0; i < 4; i++) {
        int16_t mv = adc_to_mv(ch[i]);
        r[6 + i*2] = mv; r[7 + i*2] = mv >> 8;
    }
    r[14] = 0; r[15] = 0;
    page_fill += REC_SIZE;
    rec_count++;
    if (page_fill >= 256) log_flush_page();
}

// Print helpers for the dump (fixed-point integers → decimal text).
static void print_centi(int16_t v) {               // 0.01 units → "29.60"
    if (v < 0) { uart_send_char('-'); v = -v; }
    uart_send_int(v / 100); uart_send_char('.');
    int f = v % 100; if (f < 10) uart_send_char('0'); uart_send_int(f);
}
static void print_mv(int16_t mv) {                 // millivolts → "1.650"
    if (mv < 0) { uart_send_char('-'); mv = -mv; }
    uart_send_int(mv / 1000); uart_send_char('.');
    int f = mv % 1000;
    if (f < 100) uart_send_char('0');
    if (f < 10)  uart_send_char('0');
    uart_send_int(f);
}

// Read every stored record back and stream it over USB as CSV-ish lines,
// framed by "LD:<count>" ... records ... "LE".
static void log_dump(void) {
    uart_send_string("LD:"); uart_send_int(rec_count); uart_send_string("\r\n");
    uint8_t r[REC_SIZE];
    for (uint32_t i = 0; i < rec_count; i++) {
        flash_read(i * REC_SIZE, r, REC_SIZE);
        uint32_t idx = r[0] | (r[1]<<8) | (r[2]<<16) | ((uint32_t)r[3]<<24);
        int16_t temp = (int16_t)(r[4] | (r[5]<<8));
        uart_send_string("LR:");
        uart_send_int(idx); uart_send_char(',');
        print_centi(temp);
        for (int c = 0; c < 4; c++) {
            int16_t mv = (int16_t)(r[6 + c*2] | (r[7 + c*2] << 8));
            uart_send_char(',');
            if (mv == 0x7FFF) uart_send_string("err"); else print_mv(mv);
        }
        uart_send_string("\r\n");
    }
    uart_send_string("LE\r\n");
}

int main(void) {
    uart_init();
    i2c_init();
    spi_init();
    timer_init(GEN_FS);                    // TIM2 tick source for the generator
    hsadc_init();                          // internal ADC + TIM3 + DMA (PA0 capture)

    // Status LEDs as push-pull outputs (2MHz)
    RCC_APB2ENR2 |= (1 << 4);              // enable GPIOC clock (for PC13)
    GPIOB_CRL &= ~(0xFF << 0);             // PB0 (D2) + PB1 (D3)
    GPIOB_CRL |=  (0x2 << 0) | (0x2 << 4);
    GPIOC_CRH &= ~(0xF << 20);             // PC13 (D1)
    GPIOC_CRH |=  (0x2 << 20);
    LED_COMM_OFF();

    delay(3000000);

    uart_send_string("\r\nDAQ Board v2.0\r\n");
    uart_send_string("================\r\n\r\n");

    // MCP4725 initial
    mcp4725_write(dac_value);
    uart_send_string("[OK] MCP4725 ready\r\n");

    // W25Q32 JEDEC ID
    flash_cs_low();
    spi_transfer(0x9F);
    uint8_t mfr = spi_transfer(0x00);
    uint8_t mem_type = spi_transfer(0x00);
    uint8_t capacity = spi_transfer(0x00);
    flash_cs_high();

    uint8_t flash_ok = (mfr == 0xEF && mem_type == 0x40 && capacity == 0x16);
    uart_send_string(flash_ok ? "[OK] W25Q32 ready\r\n" : "[!!] W25Q32 error\r\n");

    uart_send_string("\r\n");

    uint32_t gen_status = 0;

    while (1) {
        poll_command();

        // --- Function-generator mode ---------------------------------------
        // When active we dedicate the loop to steady waveform output (no sensor
        // I2C, which shares the same bus). Each timer tick advances the DDS
        // phase and drives the DAC; a status line is sent ~4x/second.
        if (gen_mode) {
            timer_wait_tick();
            gen_phase += gen_tw;
            mcp4725_write(gen_sample());
            if (++gen_status >= GEN_FS / 4) {
                gen_status = 0;
                uart_send_string("G:");
                uart_send_int(gen_mode);
                uart_send_char(':');
                uart_send_int(gen_freq);
                uart_send_string("\r\n");
                LED_HB_TOGGLE();
                LED_DAC_ON();
            }
            continue;
        }

        // --- PYNQ test-signal mode -----------------------------------------
        // Stream one block of SIG_N samples = clean low sine + a high-frequency
        // component at fs/4, as "FX:v0,v1,...". The FPGA FIR (a 4-tap moving
        // average) nulls the fs/4 component, so the PYNQ plot shows noisy in →
        // clean out. No sensor telemetry while streaming.
        if (sig_mode) {
            uint32_t ph_lo = 0, ph_hi = 0;
            uart_send_string("FX:");
            for (int i = 0; i < SIG_N; i++) {
                int16_t lo = (int16_t)sine64[ph_lo >> 26] - 2048;   // clean sine
                int16_t hi = (int16_t)sine64[ph_hi >> 26] - 2048;   // fs/4 "noise"
                uart_send_int(lo + hi / 2);
                if (i < SIG_N - 1) uart_send_char(',');
                ph_lo += 67108864u;     // 4 cycles over 256 samples (low freq)
                ph_hi += 1073741824u;   // 64 cycles over 256 samples = fs/4
            }
            uart_send_string("\r\n");
            LED_HB_TOGGLE();
            delay(400000);              // ~throttle blocks
            continue;
        }

        // TMP117
        uint16_t raw = 0;
        int temp_ok = (i2c_read_reg16(TMP117_ADDR, TMP117_TEMP_REG, &raw) == 0);
        int temp_x100 = temp_ok ? (((int16_t)raw) * 100) / 128 : 0;

        // Read all 4 ADC channels
        int32_t ch[4];
        for (int i = 0; i < 4; i++) {
            ch[i] = read_adc_channel(i);
        }

        // Output format: T:29.60|A0:0.580|A1:0.123|A2:0.456|A3:0.789|D:2048|P:1
        // A failed read is sent as "err" so the host can distinguish it.
        uart_send_string("T:");
        if (temp_ok) {
            int integer = temp_x100 / 100;
            int decimal = temp_x100 % 100;
            if (decimal < 0) decimal = -decimal;
            uart_send_int(integer);
            uart_send_char('.');
            if (decimal < 10) uart_send_char('0');
            uart_send_int(decimal);
        } else {
            uart_send_string("err");
        }

        for (int i = 0; i < 4; i++) {
            uart_send_string("|A");
            uart_send_char('0' + i);
            uart_send_char(':');
            send_voltage(ch[i]);
        }

        uart_send_string("|D:");
        uart_send_int(dac_value);
        uart_send_string("|P:");
        uart_send_char('0' + adc_pga);

        uart_send_string("\r\n");

        // Datalogger: store this sample to flash and report state
        if (logging) log_append((int16_t)temp_x100, ch);
        uart_send_string("LG:");
        uart_send_int(logging);
        uart_send_char(':');
        uart_send_int(rec_count);
        uart_send_string("\r\n");

        // Status LEDs
        LED_HB_TOGGLE();                        // D2: heartbeat
        if (dac_value > 0) LED_DAC_ON();        // D1: DAC output active
        else LED_DAC_OFF();
        if (comm_activity > 0) {                // D3: comms activity
            comm_activity--;
            LED_COMM_ON();
        } else {
            LED_COMM_OFF();
        }

        delay(60000);
    }
}

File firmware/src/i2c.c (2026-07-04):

#include "i2c.h"

// STM32F103 I2C1 registers (PB6=SCL, PB7=SDA)
#define RCC_BASE        0x40021000
#define RCC_APB1ENR     (*(volatile uint32_t *)(RCC_BASE + 0x1C))
#define RCC_APB2ENR     (*(volatile uint32_t *)(RCC_BASE + 0x18))

#define GPIOB_BASE      0x40010C00
#define GPIOB_CRL       (*(volatile uint32_t *)(GPIOB_BASE + 0x00))

#define I2C1_BASE       0x40005400
#define I2C1_CR1        (*(volatile uint32_t *)(I2C1_BASE + 0x00))
#define I2C1_CR2        (*(volatile uint32_t *)(I2C1_BASE + 0x04))
#define I2C1_OAR1       (*(volatile uint32_t *)(I2C1_BASE + 0x08))
#define I2C1_DR         (*(volatile uint32_t *)(I2C1_BASE + 0x10))
#define I2C1_SR1        (*(volatile uint32_t *)(I2C1_BASE + 0x14))
#define I2C1_SR2        (*(volatile uint32_t *)(I2C1_BASE + 0x18))
#define I2C1_CCR        (*(volatile uint32_t *)(I2C1_BASE + 0x1C))
#define I2C1_TRISE      (*(volatile uint32_t *)(I2C1_BASE + 0x20))

#define TIMEOUT 100000

static int wait_flag(volatile uint32_t *reg, uint32_t flag) {
    uint32_t t = TIMEOUT;
    while (!(*reg & flag) && --t);
    return t ? 0 : -1;
}

// Release the bus after an error: generate STOP so peripherals/lines don't
// stay latched. Returns -1 for convenient `return i2c_abort();`.
static int i2c_abort(void) {
    I2C1_CR1 |= (1 << 9);   // STOP
    return -1;
}

// If the peripheral is stuck BUSY (e.g. a previous aborted transfer), a
// software reset clears it and re-initialises. Called at the start of each
// transaction as a cheap self-heal.
static void i2c_ensure_ready(void) {
    uint32_t t = TIMEOUT;
    while ((I2C1_SR2 & (1 << 1)) && --t);   // wait while BUSY
    if (t == 0) {
        // Bus still busy: reset the I2C peripheral and reconfigure.
        I2C1_CR1 |= (1 << 15);              // SWRST
        I2C1_CR1 &= ~(1 << 15);
        I2C1_CR2 = 8;
        I2C1_CCR = 40;
        I2C1_TRISE = 9;
        I2C1_CR1 |= (1 << 0);              // PE
    }
}

void i2c_init(void) {
    // Enable clocks: GPIOB + I2C1
    RCC_APB2ENR |= (1 << 3);           // IOPBEN
    RCC_APB1ENR |= (1 << 21);          // I2C1EN

    // PB6 (SCL) and PB7 (SDA): alternate function open-drain
    // CRL[27:24] = PB6 = 0xF (50MHz AF open-drain)
    // CRL[31:28] = PB7 = 0xF (50MHz AF open-drain)
    GPIOB_CRL &= ~(0xFF << 24);
    GPIOB_CRL |=  (0xFF << 24);

    // Reset I2C
    I2C1_CR1 |= (1 << 15);     // SWRST
    I2C1_CR1 &= ~(1 << 15);

    // Configure I2C: 8MHz APB1, 100kHz standard mode
    I2C1_CR2 = 8;               // FREQ = 8MHz (HSI)
    I2C1_CCR = 40;              // CCR = 8MHz / (2 * 100kHz)
    I2C1_TRISE = 9;             // TRISE = 8 + 1
    I2C1_CR1 |= (1 << 0);      // PE (peripheral enable)
}

int i2c_read_reg16(uint8_t addr, uint8_t reg, uint16_t *value) {
    i2c_ensure_ready();

    // Send START + address + register
    I2C1_CR1 |= (1 << 8);                                    // START
    if (wait_flag(&I2C1_SR1, 1 << 0)) return i2c_abort();    // SB

    I2C1_DR = (addr << 1) | 0;                                // Address + Write
    if (wait_flag(&I2C1_SR1, 1 << 1)) return i2c_abort();    // ADDR
    (void)I2C1_SR2;                                            // Clear ADDR

    I2C1_DR = reg;                                             // Register address
    if (wait_flag(&I2C1_SR1, 1 << 7)) return i2c_abort();    // TxE

    // Repeated START for read
    I2C1_CR1 |= (1 << 8);                                    // START
    if (wait_flag(&I2C1_SR1, 1 << 0)) return i2c_abort();    // SB

    I2C1_CR1 |= (1 << 10);                                    // ACK
    I2C1_DR = (addr << 1) | 1;                                // Address + Read
    if (wait_flag(&I2C1_SR1, 1 << 1)) return i2c_abort();    // ADDR
    (void)I2C1_SR2;                                            // Clear ADDR

    // Read MSB (ACK)
    if (wait_flag(&I2C1_SR1, 1 << 6)) return i2c_abort();    // RxNE
    uint8_t msb = I2C1_DR;

    // Read LSB (NACK + STOP)
    I2C1_CR1 &= ~(1 << 10);                                   // NACK
    I2C1_CR1 |= (1 << 9);                                     // STOP
    if (wait_flag(&I2C1_SR1, 1 << 6)) return -1;             // RxNE (STOP already set)
    uint8_t lsb = I2C1_DR;

    *value = (msb << 8) | lsb;
    return 0;
}

int i2c_write_reg16(uint8_t addr, uint8_t reg, uint16_t value) {
    i2c_ensure_ready();

    I2C1_CR1 |= (1 << 8);                                    // START
    if (wait_flag(&I2C1_SR1, 1 << 0)) return i2c_abort();    // SB

    I2C1_DR = (addr << 1) | 0;                                // Address + Write
    if (wait_flag(&I2C1_SR1, 1 << 1)) return i2c_abort();    // ADDR
    (void)I2C1_SR2;

    I2C1_DR = reg;
    if (wait_flag(&I2C1_SR1, 1 << 7)) return i2c_abort();    // TxE

    I2C1_DR = (value >> 8);                                   // MSB
    if (wait_flag(&I2C1_SR1, 1 << 7)) return i2c_abort();

    I2C1_DR = (value & 0xFF);                                 // LSB
    if (wait_flag(&I2C1_SR1, 1 << 7)) return i2c_abort();

    I2C1_CR1 |= (1 << 9);                                     // STOP
    return 0;
}

int i2c_write_bytes(uint8_t addr, const uint8_t *data, int len) {
    i2c_ensure_ready();

    I2C1_CR1 |= (1 << 8);                                    // START
    if (wait_flag(&I2C1_SR1, 1 << 0)) return i2c_abort();    // SB

    I2C1_DR = (addr << 1) | 0;                                // Address + Write
    if (wait_flag(&I2C1_SR1, 1 << 1)) return i2c_abort();    // ADDR
    (void)I2C1_SR2;

    for (int i = 0; i < len; i++) {
        I2C1_DR = data[i];
        if (wait_flag(&I2C1_SR1, 1 << 7)) return i2c_abort();
    }

    I2C1_CR1 |= (1 << 9);                                     // STOP
    return 0;
}

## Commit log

2026-07-04 Initial commit: DAQ Board — hardware, firmware, dashboard
    STM32F103-based data acquisition board designed in Altium and brought up
    with bare-metal firmware. Includes:
    - Altium project source + Gerbers + BOM + DRC
    - Bare-metal firmware (I2C/SPI/UART drivers, no HAL)
    - Node.js + WebSocket live dashboard
    - Bring-up photos and schematic audit documentation
    [DAQ_Board.GBL, DAQ_Board.GBO, DAQ_Board.GBP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]
2026-07-04 Firmware hardening, robust dashboard, and build tooling
    Firmware:
    - I2C: STOP on every error path + BUSY self-heal to prevent bus lockups
    - ADC: wait for conversion by polling the OS bit instead of a blind delay
    - Fix int32 overflow in the volt conversion (use 64-bit math)
    - Report failed reads as 'err' instead of a plausible-looking value
    - Complete the Cortex-M3 core vector table
    - USART1 to 115200 baud
    Dashboard/server:
    - Auto-detect the CH340 serial port; reconnect on unplug; no more crashes
    - Redesigned instrument-style UI with connection state and error display
    Tooling:
    - Makefile + build.ps1/flash.ps1, README, learning docs (docs/)
    [i2c.c, main.c, uart.c]
2026-07-04 Add photo of the 5 assembled boards to README
2026-07-04 README: full visual walkthrough — design, fab, board, bring-up, dashboard
    Rename images to clean ordered names and present all 15 photos as a
    start-to-finish story: Altium design -> JLCPCB manufacturing -> the boards
    -> bring-up (blink, sensors, DAC, flash) -> live dashboard.
2026-07-11 Add DAC function generator (DDS) with interrupt-driven UART
    - TIM2 timer driver as a fixed-rate tick source
    - Direct Digital Synthesis: phase accumulator + 64-point wavetable drives
    the MCP4725 DAC (sine, square, triangle, sawtooth), adjustable frequency
    - Move UART RX to an interrupt so command bytes are never lost while the
    CPU is busy generating (fixes overrun in generator mode)
    - Dashboard: function generator panel (waveform + frequency), state sync
    - Validated on hardware by RMS measurement vs signal theory (no scope)
    [main.c, timer.c, uart.c]
2026-07-11 Add datalogger: record samples to W25Q32 flash, dump over USB
    - Restore W25Q32 write/erase/read helpers and add page-buffered logging:
    16-byte records buffered a page at a time, sectors erased on demand
    - LOG:1/0/2 commands = start / stop / dump; dump streams stored records
    back over USB as CSV-style lines
    - Dashboard: datalogger panel (Record / Stop / Download) with live count
    and CSV download of the flash contents
2026-07-11 Add high-speed capture: internal ADC on PA0 via timer + DMA
    - hsadc module: STM32 ADC1 on PA0 triggered by TIM3 TRGO, results moved by
    DMA1 into RAM (CPU-free acquisition, tens of kSPS)
    - CAP:<rate> command captures 480 samples and streams them back
    - Dashboard: high-speed capture panel (rate + Capture/Live) that plots the
    block as a software oscilloscope
    - Gives an accessible fast analog input on the J2 header (PA0), unlike the
    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
2026-07-15 Add PYNQ FPGA integration: DAQ Board -> FIR -> PC
    - Firmware: SIG command streams a test signal (sine + f_s/4 noise) over UART
    - pynq/: Python demo that reads the board over serial, pushes samples through
    the Zynq FIR via AXI-Lite, and plots input vs filtered output
    - README: system-integration section (PCB -> FPGA -> PC) with photos of the
    setup, the AXI Din test, and the input-vs-filtered plot; roadmap #4 done
    - Ties the three portfolio projects (PCB, FPGA, embedded) into one signal chain
    [main.c]
